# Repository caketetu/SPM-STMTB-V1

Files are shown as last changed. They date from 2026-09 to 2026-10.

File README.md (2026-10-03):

# SPM-STMTB-LVSD





## 概要

SPM-STMTBを使用した低電圧バイポーラステッピングモータードライバ(Low Voltage Stepping motor Driver)
ドライバICはToshibaのTC78S600FTGを使用。\
https://toshiba.semicon-storage.com/jp/semiconductor/product/motor-driver-ics/stepping-motor-driver-ics/detail.TC78S600FTG.html

## 機能

* ステッピングモーターの定電流制御
* 速度制御モード、位置制御モード
* 自動加減速制御
* RS485,CANインターフェース
* Enable信号入力
* リミットセンサーによる原点復帰、リミット停止
* エンコーダー入力による脱調検知 

## ピンアサイン
| Function | Pin  | 備考 |
| --- | ---- | ---- |
| TIM2_CH1 | PA0  | ENC-A |
| TIM2_CH2 | PA1  | ENC-B |
| USART2_TX | PA2  | SYS-RS485 |
| GPIO_Input | PA3  | H_LIMIT |
| GPIO_Input | PA4  | L_LIMIT |
| SPI1_SCK | PA5  | SYS-SPI |
| SPI1_MISO | PA6  | SYS-SPI |
| SPI1_MOSI | PA7  | SYS-SPI |
| TIM1_CH1 | PA8  |  CK |
| USART1_TX | PA9  |  SYS-UART |
| USART1_RX | PA10 |  SYS-UART |
| FDCAN1_RX | PA11 |  SYS-CANFD |
| FDCAN1_TX | PA12 |  SYS-CANFD |
| DEBUG_SWDIO | PA13 |  SYS-DEBUG |
| DEBUG_SWCLK | PA14 |  SYS-DEBUG |
| USART2_RX | PA15 |  SYS-RS485 |
| SPI1_NSS | PB0  |  SYS-SPI |
| GPIO_Output | PB1  |  STBY |
| GPIO_Output | PB2  |  CW/CCW |
| GPIO_Output | PB3  |  M1 |
| GPIO_Output | PB4  |  SYS-LED1 |
| GPIO_Input | PB5  |  SYS-EN |
| GPIO_Output | PB6  |  M2 |
| GPIO_Output | PB7  |  ENABLE |
| GPIO_Output | PB8  |  TQ |
| GPIO_Input | PB9  | HOME |
| GPIO_Output | PC6  | SYS-LED0 |
| RCC_OSCIN | PC14 | SYS-CLOCK |
| RCC_OSCOUT | PC15 | SYS-CLOCK |
| RCC_MCO | PF2  | SYS-DEBUG |

※SYS-はSPM共通インターフェース

## 開発環境

| 項目 | 内容 |
| --- | --- |
| MCU | STM32C092KBT6 |
| IDE | STM32CubeIDE for VSCode |
| CubeMX | STM32CubeMX 6.15.0 |
| Firmware | STM32CubeC0 |
| Language | C |

## 実装予定機能

* [ ] CAN通信
* [ ] リミット検知
* [ ] 原点復帰
* [ ] エンコーダー脱調検知

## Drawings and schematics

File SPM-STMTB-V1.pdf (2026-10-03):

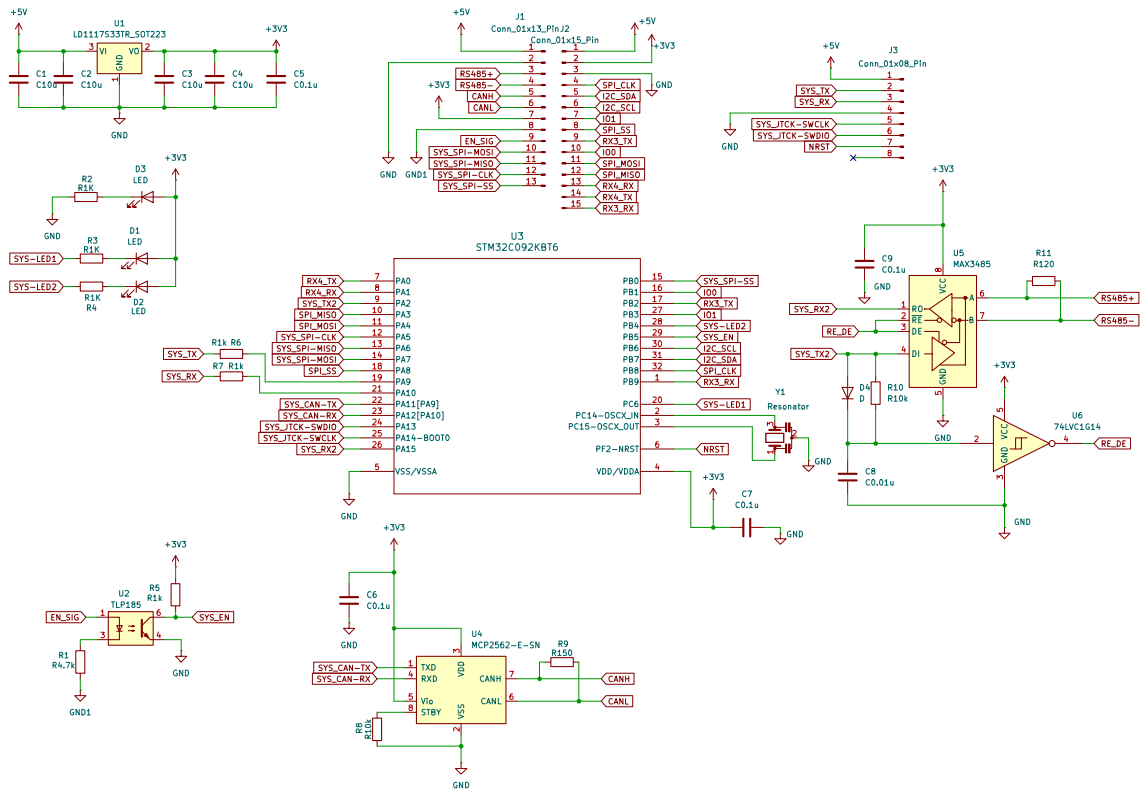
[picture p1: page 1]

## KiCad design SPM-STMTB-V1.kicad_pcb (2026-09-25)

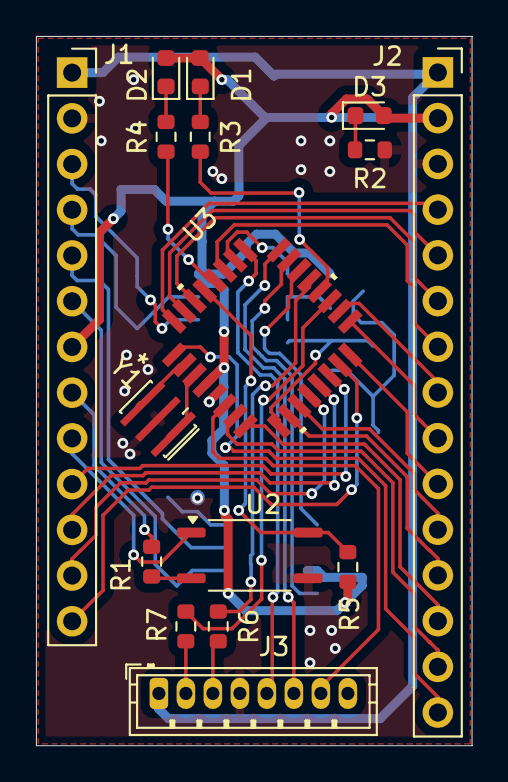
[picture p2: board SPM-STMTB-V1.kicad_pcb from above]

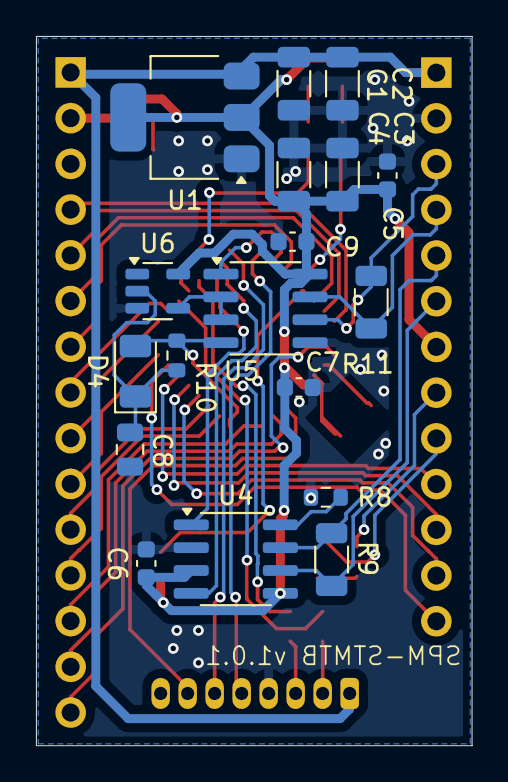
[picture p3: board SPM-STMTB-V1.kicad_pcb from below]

Board: 2 copper layers, 24.2 x 39.4 mm, 34 parts (18 on the bottom side), 48 nets.

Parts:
C1, C2, C3, C4: C10u; C_1206_3216Metric
C5, C6, C7, C9: C0.1u; C_0603_1608Metric
C8: C0.01u; C_0805_2012Metric
D1, D2, D3: LED; LED_0603_1608Metric
D4: D; D_1206_3216Metric
J1: Conn_01x13_Pin; PinSocket_1x13_P2.54mm_Vertical
J2: Conn_01x15_Pin; PinSocket_1x15_P2.54mm_Vertical
J3: Conn_01x08_Pin; JST_ZH_B8B-ZR_1x08_P1.50mm_Vertical
R1: R4.7k; R_0603_1608Metric
R2, R3, R4: R1K; R_0603_1608Metric
R5, R6, R7: R1k; R_0603_1608Metric
R8: R150; R_0603_1608Metric
R9: R150; R_1206_3216Metric
R10: R10k; R_0603_1608Metric
R11: R120; R_1206_3216Metric
U1: LD1117S33TR_SOT223; SOT-223-3_TabPin2
U2: TLP185; SOIC-4_4.55x3.7mm_P2.54mm
U3: STM32C092KBT6; LQFP-32_STM
U4: MCP2562-E-SN; SOIC-8_3.9x4.9mm_P1.27mm
U5: MAX3485; SOIC-8_3.9x4.9mm_P1.27mm
U6: 74LVC1G14; SOT-23-5
Y1: Resonator; Resonator_SMD_Murata_CSTxExxV-3Pin_3.0x1.1mm_HandSoldering

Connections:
+3V3: C3.1, C4.1, C5.1, C6.1, C7.1, C9.1, D1.2 (A), D2.2 (A), D3.2 (A), J1.7, J2.2, R5.1, U1.2 (VO), U3.4 (VDD/VDDA), U4.3 (VDD), U4.5 (Vio), U5.8 (VCC), U6.5 (VCC)
+5V: C1.1, C2.1, J1.1, J2.1, J3.1, U1.3 (VI)
CANH: J1.5, R9.1, U4.7 (CANH)
CANL: J1.6, R9.2, U4.6 (CANL)
EN_SIG: J1.9, U2.1
GND: C1.2, C2.2, C3.2, C4.2, C5.2, C6.2, C7.2, C8.2, C9.2, J1.2, J2.3, J3.4, R2.1, R8.1, U1.1 (GND), U2.4, U3.5 (VSS/VSSA), U4.2 (VSS), U5.5 (GND), U6.3 (GND), Y1.2
GND1: J1.8, R1.2
I2C_SCL: J2.6, U3.30 (PB6)
I2C_SDA: J2.5, U3.31 (PB7)
IO0: J2.10, U3.16 (PB1)
IO1: J2.7, U3.27 (PB3)
NRST: J3.7, U3.6 (PF2-NRST)
unnamed: D1.1 (K), R3.2
unnamed: D2.1 (K), R4.2
unnamed: D3.1 (K), R2.2
unnamed: C8.1, D4.1 (K), R10.2, U6.2
unnamed: R1.1, U2.3
unnamed: R6.1, U3.19 (PA9)
unnamed: R7.2, U3.21 (PA10)
unnamed: U3.2 (PC14-OSCX_IN), Y1.3
unnamed: U3.3 (PC15-OSCX_OUT), Y1.1
unnamed: R8.2, U4.8 (STBY)
RE_DE: U5.2 (~RE), U5.3 (DE), U6.4
RS485+: J1.3, R11.1, U5.6 (A)
RS485-: J1.4, R11.2, U5.7 (B)
RX3_RX: J2.15, U3.1 (PB9)
RX3_TX: J2.9, U3.17 (PB2)
RX4_RX: J2.13, U3.8 (PA1)
RX4_TX: J2.14, U3.7 (PA0)
SPI_CLK: J2.4, U3.32 (PB8)
SPI_MISO: J2.12, U3.10 (PA3)
SPI_MOSI: J2.11, U3.11 (PA4)
SPI_SS: J2.8, U3.18 (PA8)
SYS-LED1: R3.1, U3.20 (PC6)
SYS-LED2: R4.1, U3.28 (PB4)
SYS_CAN-RX: U3.23 (PA12[PA10]), U4.4 (RXD)
SYS_CAN-TX: U3.22 (PA11[PA9]), U4.1 (TXD)
SYS_EN: R5.2, U2.6, U3.29 (PB5)
SYS_JTCK-SWCLK: J3.5, U3.25 (PA14-BOOT0)
SYS_JTCK-SWDIO: J3.6, U3.24 (PA13)
SYS_RX: J3.3, R7.1
SYS_RX2: U3.26 (PA15), U5.1 (RO)
SYS_SPI-CLK: J1.12, U3.12 (PA5)
SYS_SPI-MISO: J1.11, U3.13 (PA6)
SYS_SPI-MOSI: J1.10, U3.14 (PA7)
SYS_SPI-SS: J1.13, U3.15 (PB0)
SYS_TX: J3.2, R6.2
SYS_TX2: D4.2 (A), R10.1, U3.9 (PA2), U5.4 (DI)

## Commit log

2026-09-25 first upload
    [SPM-STMTB-V1.kicad_pcb, SPM-STMTB-V1.kicad_sch, freerouting.dsn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]
2026-10-03 PTr電流制限抵抗の変更
    [SPM-STMTB-V1.kicad_sch]
